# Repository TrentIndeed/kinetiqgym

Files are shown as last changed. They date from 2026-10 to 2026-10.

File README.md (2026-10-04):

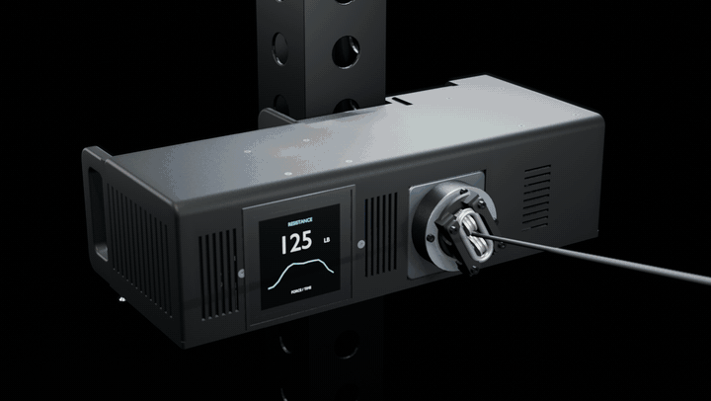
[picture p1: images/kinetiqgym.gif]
KinetiqGym: covers off, the drivetrain turning
<p align="center"></p>

<h1 align="center">KinetiqGym</h1>
<p align="center"><b>An open-source, battery-powered cable trainer you can print, build and modify.</b><br>
<a href="https://kinetiqgym.com">kinetiqgym.com</a> · <a href="docs/build.md">Build</a> · <a href="docs/wiring.md">Wiring</a> · <a href="bom/BOM.md">Parts</a> · <a href="cad/">CAD</a> · <a href="images/animation.mp4">Video</a></p>

A direct-drive motor turns a rope drum, a geared level-wind fairlead lays the rope, and the controller sets the resistance.
Designed to be 3D printed (with two drilled aluminium bars) or machined, and to be adapted: other motors, other batteries,
a rotary encoder instead of the touch screen.

> **Status: v0.1.0, prototype design. Not yet built or load-tested.** Read [SAFETY.md](SAFETY.md) before building.
> The control app is not included yet.

**Upcoming:** updated CAD models, the confirmed parts list and build instructions, phone/touchscreen apps, and Pi/Teensy programs. The files here are an earlier prototype snapshot. The website includes an [illustrated CNC build preview](https://kinetiqgym.com/docs/cnc-build-preview.html), mechanism camera views and app concepts from the latest animation.

Want to help? [Propose an improvement](https://github.com/TrentIndeed/kinetiqgym/issues/new?template=proposal.yml), read the [maintainer review process](CONTRIBUTING.md), or visit [project support](https://kinetiqgym.com/#support) for CNC equipment and prototype testing.

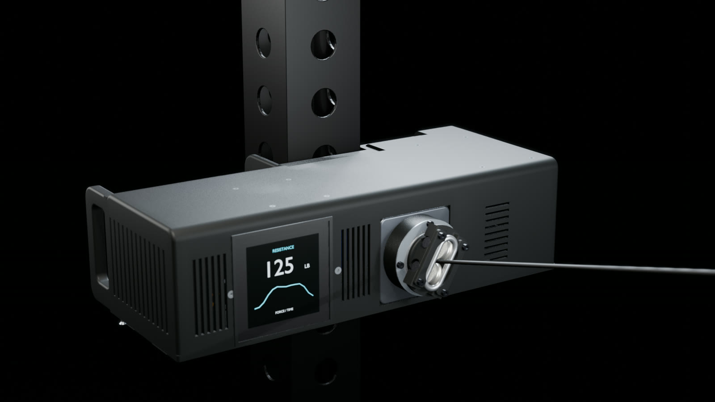
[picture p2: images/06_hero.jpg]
KinetiqGym on a rack upright


| | |
|---|---|
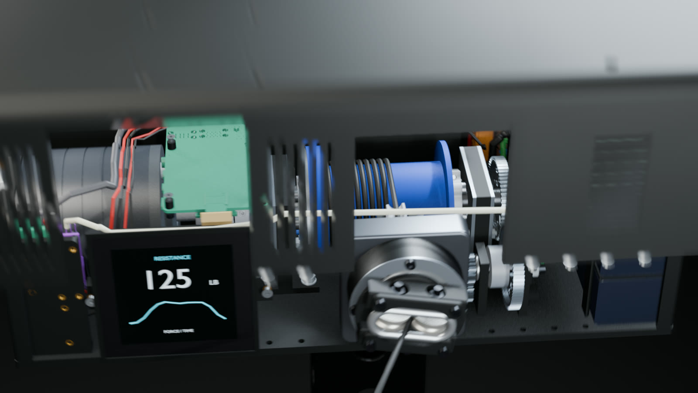
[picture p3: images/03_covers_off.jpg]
Covers off
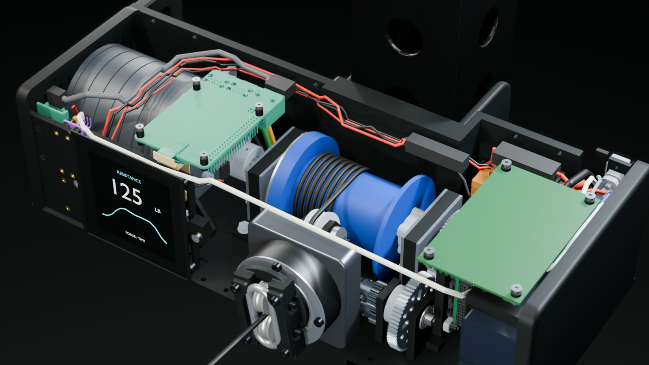
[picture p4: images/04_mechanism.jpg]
The mechanism
|  |  |
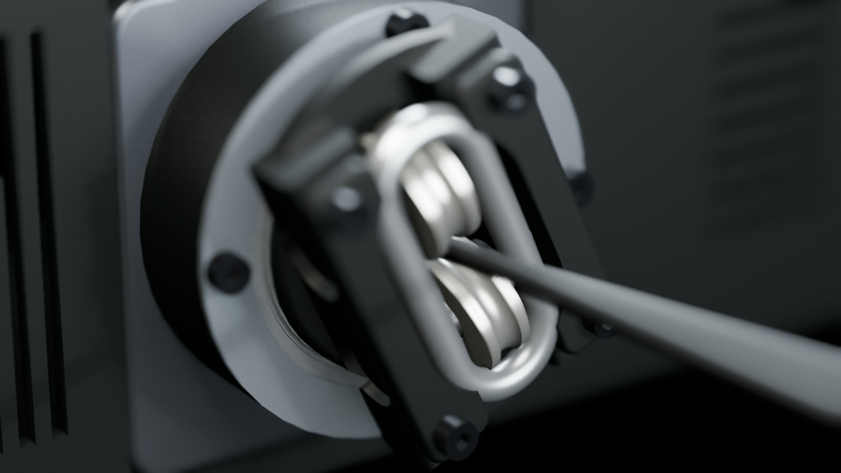
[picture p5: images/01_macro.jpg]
The fairlead exit
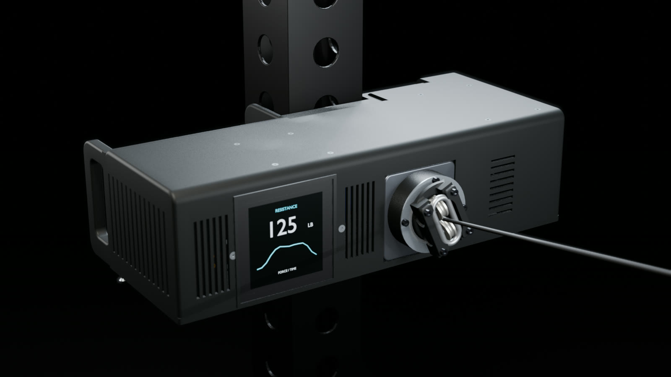
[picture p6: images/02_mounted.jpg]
Mounted on a rack
|  |  |
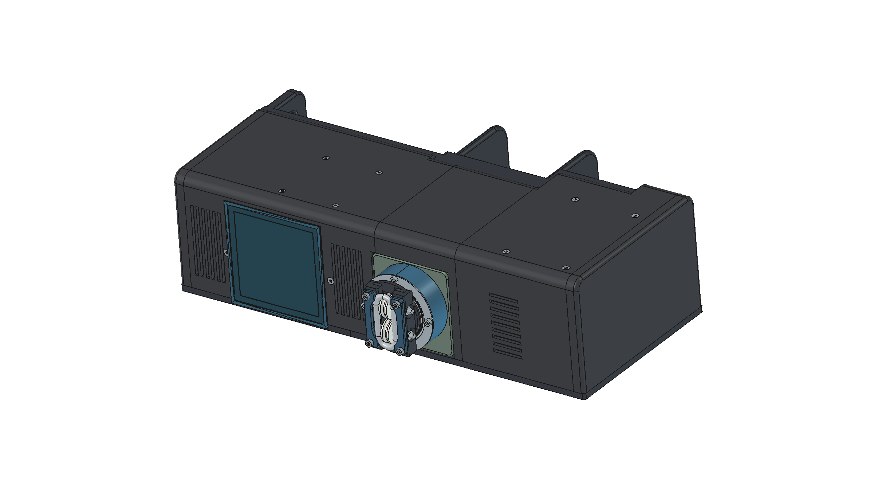
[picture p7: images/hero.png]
The CAD, covers on
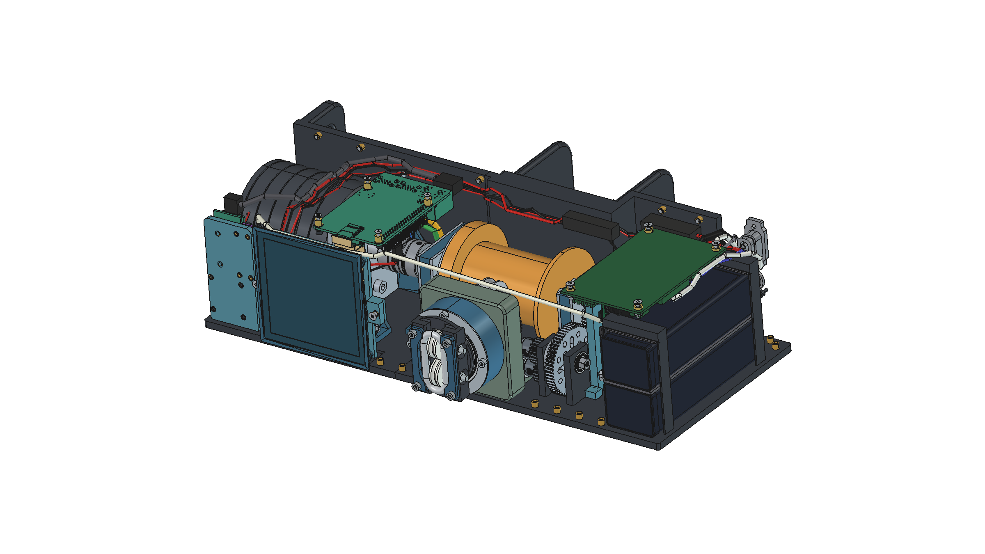
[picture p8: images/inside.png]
The CAD, covers off
|  |  |

<sub>Renders: Blender (Eevee) from the CAD in this repository, the mechanism moving at its real gear ratios; the display
content is illustrative. Bottom row: the FreeCAD assembly.</sub>

## At a glance

| | |
|---|---|
| Drive | direct-drive outrunner (reference: about 50 Kv, 13 N·m peak) on an ODrive Pro |
| Resistance | 100 lbf sustained design target; physical load and thermal validation pending |
| Rope | 3.175 mm (1/8 in), 2.11 m tracked payout + 3 dead wraps; design load 890 N (200 lbf) |
| Fairlead | worm-driven carrier (1/53 of a turn per drum turn) with a sheave and a U625ZZ pulley exit |
| Battery | 2 x 5S LiPo (Thunder Power TP2700-5SR70) in series, 30-42 V, JBD 10S BMS; regenerative braking charges it |
| Controls | Raspberry Pi 4 + 4 in touch screen, Teensy 4.0 on CAN to the ODrive |
| Size | about 371 x 143 x 112 mm, about 6 L, about 5.6 kg (estimate) |
| Parts | 28 printed parts, 136 screws / nuts / washers / inserts, about 55 purchased components |

## What is in this repository

| Folder | Contents |
|---|---|
| [`cad/freecad/`](cad/freecad/) | FreeCAD 1.x: the assembly, one file per part **with its full feature history**, and a drivetrain motion study |
| [`cad/step/`](cad/step/) | every part as STEP, plus one assembly STEP per variant |
| [`cad/dxf/`](cad/dxf/) | 2-D profiles of the flat parts |
| [`cad/vendor/`](cad/vendor/) | where to download the supplier CAD (bearings, gears, boards...) that cannot be redistributed |
| [`print/`](print/) | STL for every printed part, with material, orientation and inserts; fit coupons |
| [`bom/`](bom/) | bill of materials: purchased parts, hardware counts, metal |
| [`docs/`](docs/) | [build](docs/build.md), [wiring](docs/wiring.md), [electronics and firmware setup](docs/firmware-setup.md), [printing](docs/printing.md), [modifying](docs/modifying.md) |
| [`site/`](site/) | Website, editable itemized budget and reference pages |
| [`software/`](software/) | Pi, Teensy and companion software status (implementation pending) |
| [`source/`](source/) | the Python (CadQuery) scripts that generate the CAD |

Two variants share the same enclosure: **printed** (PA-CF bottom plate on two aluminium flat bars) and **cnc**
(aluminium bottom plate).

## Licences

- Hardware (CAD, drawings, print files): **CERN-OHL-S-2.0**
- Documentation and images: **CC BY-SA 4.0**
- Software and scripts (`source/`): **GPL-3.0**

See [LICENSE.md](LICENSE.md). Supplier CAD is not included; each supplier's own terms apply to the files you download.

## Contributing

Issues and pull requests are welcome: see [CONTRIBUTING.md](CONTRIBUTING.md).

## Development status and budget

See [the roadmap](docs/roadmap.md) for release milestones and [the website](https://kinetiqgym.com/#parts) for itemized purchasing prices, dated sources and editable fabrication allowances. The budget is a planning estimate, excluding tax, shipping, tools, labor and the rack.

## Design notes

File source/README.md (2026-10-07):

# Build scripts (GPL-3.0)

The Python / CadQuery scripts that generate every part, the fasteners, the wiring and the FreeCAD files.
They are the source of truth for the CAD. In this release they still expect the full design workspace (supplier CAD and the
interactive layout data are not published), so treat them as readable source; a self-contained build is planned.

- `print-v44/run_v44.sh`: the V44 pipeline (parts -> structure -> enclosure -> fasteners -> wiring -> checks)
- `mounts-rev11/`: brackets, saddles, board plates; `stock-drive-study/`: the fairlead module
- `fchist/`: records the CadQuery history and writes the FreeCAD files; `release/`: builds this repository

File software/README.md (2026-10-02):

# Control software — planned

No installable KINETIQ Pi application, Teensy firmware or Bluetooth companion is included in this release. The product film demonstrates the intended interface only.

Planned locations:

- `pi/`: built-in touchscreen application; resistance, rep graph and mode controls.
- `teensy/`: real-time control, position limits and ODrive communication.
- `companion/`: Bluetooth browser interface, richer settings and workout history.

These directories will be added with their implementations. Follow [the roadmap](../docs/roadmap.md) and [electronics setup reference](../docs/firmware-setup.md) for project status.

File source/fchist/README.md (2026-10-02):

# fchist: the V44 parts in FreeCAD, with their feature history

The Python build scripts stay the source of truth. While they run with `FCHIST=1`, every CadQuery modelling call is
recorded, and `to_freecad.py` turns that record into FreeCAD part files with a real feature tree: primitives,
booleans, fillets and moves that you can open, read and edit.

```
record_run.sh       one pipeline run with recording on (fairlead module -> rev-11 mounts -> V44 pipeline; same geometry)
make_freecad.sh     FreeCAD files -> cad/single-cable/freecad/<printed|cnc>/   (./make_freecad.sh [printed|cnc|both] [part prefix ...])
```

## What you get

`freecad/<variant>/V44_<variant>_assembly.FCStd` links every part (one `App::Link` per part, grouped by subsystem, coloured,
the "complete" view shown). A part that takes heat-set inserts is an `App::Part` holding the part and its inserts, so they move together. Each part is its own file in `freecad/<variant>/parts/<part>.FCStd`.

Open a part and expand its tree. The top feature is the finished part and holds the whole build:

| Pipeline call | FreeCAD feature |
|---|---|
| `Solid.makeBox / makeCylinder / makeCone / makeSphere / makeTorus` | `Part::Box / Cylinder / Cone / Sphere / Torus` (size + Placement) |
| `cut`, `fuse`, `intersect` | `Part::Cut` (several tools: a `MultiFuse` of the tools), `Part::MultiFuse`, `Part::MultiCommon` |
| `translate`, `rotate`, `moved`, `transformShape`, page placements | the Placement of the feature they move |
| `mirror` | `Part::Mirroring` |
| `clean` | `Part::Refine` |
| `fillet`, `chamfer` | `Part::Fillet`, `Part::Chamfer` (edges found again by position) |
| `Compound.makeCompound` | `Part::Compound` |
| anything else (wire extrusions, text, sweeps, picking one solid, supplier CAD, mesh-rebuilt page parts) | a `Base:` feature holding the exact shape |

Each feature's label names the script line that made it (for example `Cut · build_v44_shell.py:142 body`), and Label2 holds
the full call site. Change a primitive's size or placement and recompute: everything after it in the tree follows.

Every part is checked against the pipeline's own shape (volume and bounding box) in `freecad-report.json`.
If a rebuilt tree does not match, the part keeps its tree and shows the exact shape on top, and the report lists it.

## Drivetrain motion (FreeCAD Assembly workbench)

`freecad/<variant>/V44_<variant>_drivetrain_motion.FCStd` (`./make_freecad.sh both --motion`, `motion.py`) is a real
Assembly-workbench study, solved by FreeCAD's own solver:

- the motor body is grounded; Revolute joints on the drum shaft, shaft 2, the worm shaft and the carrier ring (6809 pivot);
- every part that turns with a shaft is Fixed to it; **Gears** joints carry drum 60T -> shaft-2 60T and shaft-2 20T -> worm-shaft 20T;
- FreeCAD has no worm-gear joint, so the carrier ring has its own motion at exactly 1/53 of the drum (direction checked: the
  worm and ring teeth never overlap through a worm turn);
- **Simulation: motor** drives the drum +-5.5 turns over 20 s (carrier +-37 deg, inside its +-48.4 deg stops).

Open the file, switch to the Assembly workbench, double-click *Simulation: motor*, press **Run** (about 3 minutes for the
1,000 frames), then **Play** or drag the frame slider. The covers are hidden; show them from the Static parts group.
Change the motor in the *Motor: drum shaft* motion (formula in radians of time, e.g. `6.28*time` = 1 turn/s; then set the
carrier motion to the same formula divided by 53). Keep the drum under about 13 deg per frame or the gear joints lose track.

## How it works

- `boot/sitecustomize.py` installs `fchist_rec.py` when `FCHIST=1` and `fchist/boot` is on `PYTHONPATH`. The build scripts are
  unchanged, apart from two direct OCP moves that now report themselves (`build_v44_phase1.py apply()`, `teensy_fit.py`).
- Each written part file gets `<file>.fch.json` (the graph back to the first primitive, with the file's hash). Reading the file in the
  next stage continues the same history, so a part made in `build_mounts.py`, placed in phase 1, cut by the shell and drilled by
  the fasteners step is one tree. Base shapes are stored once, by content hash, in `cad/single-cable/.fchist/blobs/` (not committed).
- History files are only trusted when the part file's hash matches, so a part rebuilt without recording falls back to its exact shape.

## Next (open-source path)

Sketches: replace the `Base:` features that come from wire extrusions (wire loops, gussets, polyline profiles) with
FreeCAD Sketcher sketches + Pad, and draw the plates and brackets from sketches instead of boxes, so the
release has editable 2-D profiles (and DXF) as well as the history.

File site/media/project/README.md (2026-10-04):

# Film stills for the project website

Source: `KINETIQ_67s_sequential_16x9_clean_shadow.mp4`, the approved Blender film with a CNC build followed by the phone app showcase.

| Image | Source |
| --- | --- |
| base.webp | 36.5 s, welded aluminum structure |
| drum.webp | 43.0 s, installed drum and fairlead |
| electronics.webp | 46.7 s, open CNC assembly |
| cover.webp | 51.4 s, finished enclosure |
| drive-angle.webp | 8.5 s, oblique mechanism view, narrator inset cropped out |
| gear-angle.webp | 11.5 s, front mechanism view, narrator inset cropped out |
| app-train/live/session/history.webp | High-resolution UI source pages used for the film |

These are design illustrations, not photographs of validated hardware or a working app. Keep that distinction when reusing them. The film assembly is a visualization revision; the updated manufacturing release remains pending.

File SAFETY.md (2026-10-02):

# Safety

**Status: prototype design. It has not been built or load-tested as published.** Treat every number here as a design value
until your own build has passed the tests below.

## What can hurt you

- **Cable load.** The machine is designed for 890 N (200 lbf) on the cable. A rope, an anchor or a printed part that fails
  under load releases that energy at the handle. Inspect the rope, the anchor wraps and the fairlead before every session;
  replace a frayed rope at once.
- **Battery.** Two 5S lithium-polymer packs in series make 30-42 V and can deliver very high current. Use the specified
  BMS and fuses, never bypass them, charge only with the BMS connected, and store and charge the packs on a fire-safe surface.
- **Motor torque.** The ODrive can drive the drum with up to about 13 N·m. Keep fingers, hair and loose clothing away from the
  drum, gears and the rope exit while it is powered.
- **Regenerative braking.** Lowering the weight charges the battery. If the BMS stops charging (full pack, over-temperature),
  the ODrive trips on over-voltage and **the cable goes slack for that rep**. Charge to about 80 % so braking energy has room.

## Rules for every build

1. **Payout limit in software.** Home the drum fully wound and set the ODrive position limits (`docs/firmware-setup.md`):
   `pos_min = 0`, `pos_max = 13.26` turns. The two hard stops on the fairlead carrier (+-48.4 deg) are only a backstop for
   assembly and hand-turning: the worm drive cannot be back-driven, so a stop hit under load locks the drum through the
   gears and can strip the m0.8 gears or break the printed lug.
2. **Keep the 3 dead wraps** of rope on the drum at full payout. Never run the rope off the drum.
3. **Fuses:** 40 A 58 V main fuse, 3 A 58 V regulator fuse, 7.5 A 58 V charge fuse. Automotive 32 V fuses are not rated for
   this pack voltage.
4. **First power-up** with the rope unloaded: check the inrush at the power button (the BMS may trip; lengthen its
   short-circuit delay in the BMS app if it does), the direction of the drum, the soft limits and the ODrive over-voltage trip.
5. **Load test** before training: hang a static load in steps up to 1.5 x your planned use, with nobody in the rope's path.
6. Print the structural parts in the specified material (PA-CF / PETG-CF), with the infill and walls in `docs/printing.md`,
   and print the fit coupons first.

## No warranty

The design is shared under the licences in `LICENSE.md` **without any warranty**. You build and use it at your own risk.

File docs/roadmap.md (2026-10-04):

# Project roadmap

KINETIQ is a prototype design. The repository contains an earlier development snapshot. Updated CAD, confirmed build instructions and parts list, app code and control programs are upcoming.

| Area | Available now | Next milestone |
|---|---|---|
| Hardware | Printed and CNC assemblies; FreeCAD feature histories, STEP, DXF and STL | Reconcile every export and manifest against one revision; prototype fit and load testing |
| Build guide | Draft references and an illustrated CNC animation preview on the website | Confirmed assembly steps, build photos and measured fit notes |
| Adaptation | Motor interface guide and battery-envelope sketch | Fully constrained sketch-based parts and a self-contained CAD generation pipeline |
| Raspberry Pi | Screen concept in the product film | Touchscreen application, reproducible image and installation guide |
| Teensy | Proposed control architecture and setup reference | Firmware, configuration schema, limits and bench test procedure |
| Companion | Phone app concept screens in the film and website | Bluetooth protocol, connection flow, mode settings and workout history |

## How releases should work

Keep one repository for the hardware, website, documentation and control software while the project is small. Each future release should identify a single compatible set of CAD, BOM, wiring and software versions. Do not mix a new part with an older assembly without recording the change.

For a hardware release, publish the editable FreeCAD sources and neutral STEP alongside STL/DXF exports, an itemized BOM, a changelog and a validation report. Label untested changes explicitly. Large production animations and build recordings belong in release assets or external media storage rather than repeated Git history.

For the Pi and Teensy, add actual source, dependency versions, build commands, configuration defaults and test instructions before advertising a software download. The current film is a UI concept, not evidence of working controls.

## Useful contributions

- Build reports: revision, manufacturing method, material, measured fit, photos and unresolved issues.
- CAD changes: source file, exported geometry, affected hardware and assembly steps.
- Alternative batteries or motors: interface dimensions, electrical compatibility assumptions and test results.
- Sourcing: exact part, region, quantity, price, currency, date and supplier link.
- Documentation: one reproducible step or correction with the affected revision.

See [CONTRIBUTING.md](../CONTRIBUTING.md) and [the license map](../LICENSE.md). Supplier CAD and controller firmware retain their own terms.

## Prototype funding

Project support is intended for a CNC machine, fabrication and prototype test equipment. The website support section explains these goals. A payment link appears only when the owner has configured the chosen donation provider; contributions are not orders for a finished product. No funding total or equipment price is implied by the concept film.

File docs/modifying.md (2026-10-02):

# Modifying the design

The design is meant to be adapted: a different motor, a rotary encoder instead of the touch screen, a different battery.
This release ships the parts as FreeCAD files with their full feature history and as STEP; fully sketch-based,
parameter-driven parts are planned for the next release.

## How the CAD is organised

- `cad/freecad/<printed|cnc>/V44_<variant>_assembly.FCStd`: the whole machine. Every part is a link to its own file in `parts/`.
  A part that takes heat-set inserts is a container holding the part and its inserts.
- `cad/freecad/<variant>/parts/<part>.FCStd`: one part with its feature tree (boxes, cylinders, cuts, fuses, fillets, moves).
  Each feature is labelled with the build-script line that made it. Change a size or a placement and recompute.
- `cad/freecad/<variant>/V44_<variant>_drivetrain_motion.FCStd`: Assembly-workbench motion study of the drivetrain.
- `cad/step/`: the same parts as STEP for any CAD program, plus one assembly STEP per variant.
- `cad/dxf/`: 2-D profiles of the flat parts.
- Supplier parts (motor driver, bearings, gears, boards...) are simple placeholders of the right size; get the real CAD
  from `cad/vendor/README.md`.
- `source/`: the Python (CadQuery) scripts that generate everything. They are the source of truth, but in this release they
  still expect the full design workspace; a self-contained build is planned.

Variants: **printed** (PA-CF bottom plate with aluminium flat bars under it) and **cnc** (aluminium bottom plate).

## Swapping the motor

What the motor touches:

| Interface | Where | Change |
|---|---|---|
| Face mount | the 4 mm motor face plate (`V43_METAL_motor_face_4mm`) + two printed gussets | hole pattern and pilot bore for your motor |
| Shaft | the NBK MSTS-25-10-12 coupling (10 mm motor, 12 mm drum shaft) | coupling bore for your shaft |
| Envelope | motor body about 80 x 82 mm at the motor end (X -77 to -3) | the end cap, covers and the board plate around it |
| Leads | three phase leads through a 12 mm grommet in the face plate to the ODrive terminal | lead exit and length |
| Electrical | ODrive Pro limits (current, voltage), torque constant | `firmware-setup.md` |

Torque at the drum is the motor torque (direct drive): the cable force is about torque / 0.025 m (rope radius on the drum).

## Swapping the batteries

1. Measure both actual packs, including leads and connector bodies. Record length, width and height; do not rely only on nominal capacity.
2. Open a copy of the assembly and the saddle/retainer part files. Edit the relevant feature dimensions. For a STEP-only workflow, import the solids, create a constrained rectangular envelope sketch, and use new additive/subtractive features for your revised mount.
3. Add padding and lead-bend clearance to the envelope. Keep the BMS, wires and mounting screws outside the straight removal path. Test both pack envelopes together, including staggered removal.
4. Recompute the covers and check intersections and retaining surfaces. Print a fit sample before committing to a full enclosure; export the updated STEP/STL and update the BOM and revision.
5. Review series count, fully charged voltage, BMS, charger, fuse/wire sizing and regenerative charge limits as a system before powered testing. Capacity alone does not establish compatibility.

The reference is two 5S packs in series (10S, 42 V fully charged). The [website adaptation guide](https://kinetiqgym.com/#modify) illustrates the pack envelope and motor interfaces. Its diagrams are measurement guides, not dimensioned manufacturing drawings.

## Rotary encoder instead of the touch screen

What the screen touches:

| Interface | Where | Change |
|---|---|---|
| Front window | the left cover (`V44_PRINT_cover_left_screen`), 4 in window | replace the window with a panel hole for the encoder (and a small display if wanted) |
| Screen frame | `MOUNT_screen_rear_retaining_frame_printed` + 2 x M3 legs into inserts | not needed |
| Pi + DSI ribbon | Raspberry Pi 4 hanging from the cover ceiling, ribbon to the screen | optional: the Teensy can run the machine alone |
| Encoder | quadrature A/B + push switch to free Teensy pins, 3.3 V | firmware |

## Contributing changes back

The hardware is CERN-OHL-S-2.0 (share-alike): if you distribute a modified version, publish your modified design files under
the same licence. Pull requests and issues are welcome: see `CONTRIBUTING.md`.

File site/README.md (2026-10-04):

# KINETIQ website

Static HTML, CSS and JavaScript. Serve this directory over HTTP:

```sh
python -m http.server 8770 --directory site
```

The editable shopping budget uses `data/project.json`; each row records quantity, unit price, price basis, applicable build and source. Unknown costs are explicit allowances. Prices are not live inventory or quotes. User edits and owned-item selections stay in browser local storage; CSV export includes the selected build.

`docs/` contains readable HTML copies of the public Markdown references. Keep both copies aligned when changing engineering documentation. The website does not contain the private hosting account configuration.

The illustrated CNC build and phone app are concept previews extracted from the Blender film. The updated CAD release, confirmed parts list, final build instructions and control software are pending. Do not present them as validated downloads.

`data/community.json` contains the public proposal email and donation checkout URL. Empty fields show honest “coming soon” states. Set `proposalEmail` to the owner's approved public address and `donationUrl` to an HTTPS checkout on the chosen provider; `donationProvider` names it in the checkout description. Payments are handled by that provider, not collected on this website. No donation totals or equipment budget are invented.

The website links to the public GitHub proposal form and contribution guide. The initial review owner is `@TrentIndeed`; `.github/CODEOWNERS` and the main-branch ruleset enforce reviews for community changes. Additional moderators must be appointed by the repository owner.

The four illustrated stages have a standalone guide in `docs/cnc-build-preview.md` and `.html`. When replacing film stills, keep their revision and concept status clear.

The owner-approved public proposal address is `trentondragon02@gmail.com`. The owner-supplied PayPal donation URL is active and its recipient was verified as Trenton Dragon on the PayPal checkout page. The goal is a Carvera Air CNC machine and prototype testing. Preserve the recipient ID and checkout parameters when editing the link; do not substitute the proposal email as a payment recipient.

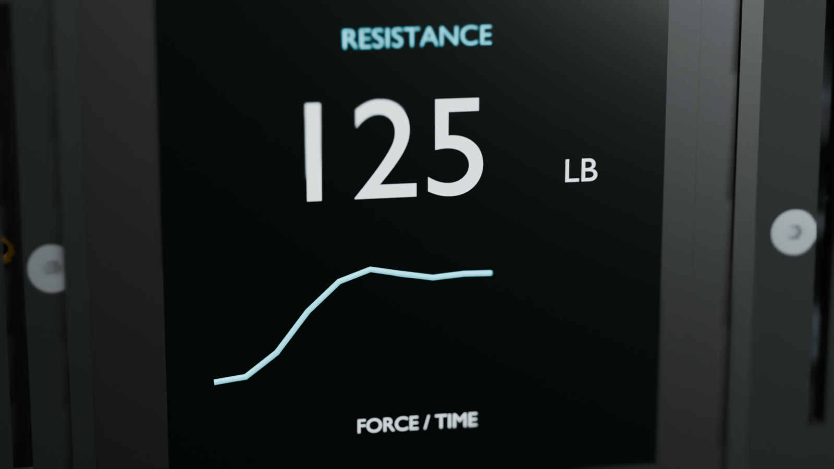
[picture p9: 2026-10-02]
site/media/05_display.jpg

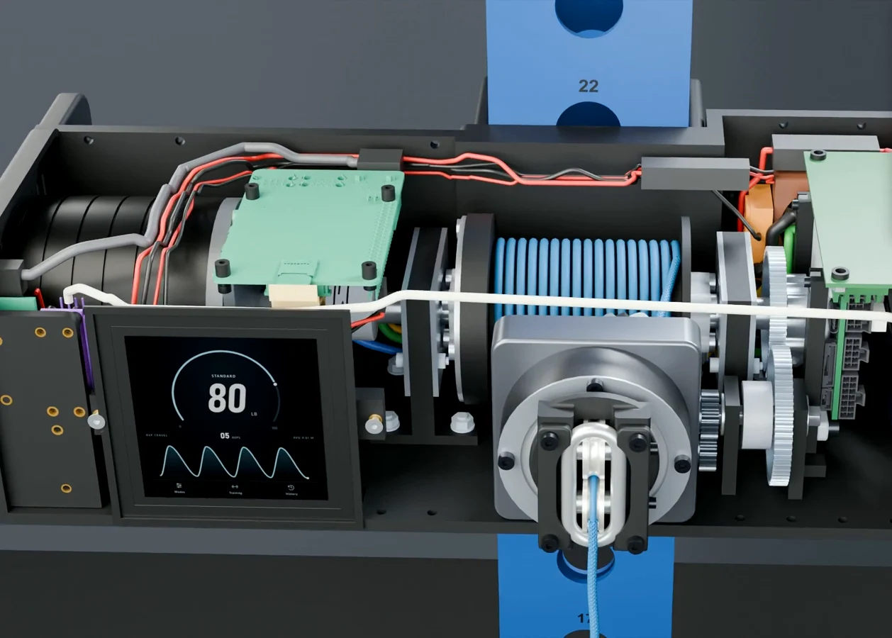
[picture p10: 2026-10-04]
site/media/project/gear-angle.webp

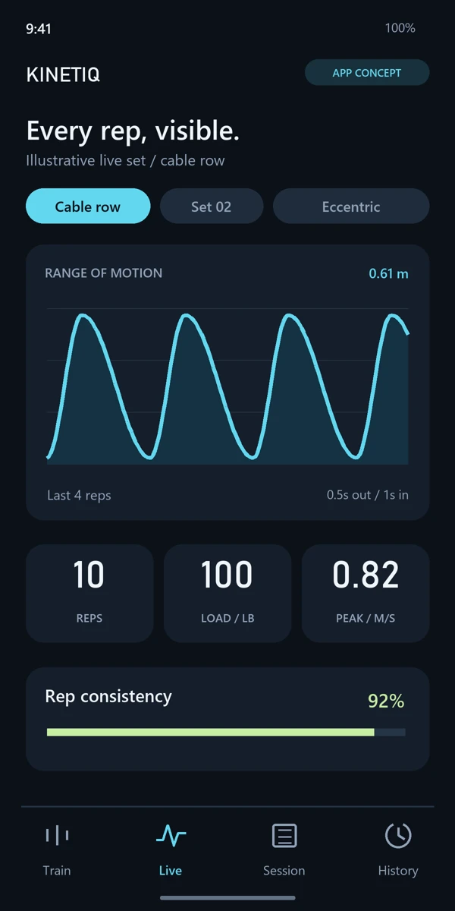
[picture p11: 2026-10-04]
site/media/project/app-live.webp

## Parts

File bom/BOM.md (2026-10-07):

# Bill of materials

Quantities are for one machine (printed variant). Links are examples checked in September 2026: pick by reviews and check the
specs. Nothing here is endorsed by the suppliers.

## Drive and fairlead

| Qty | Part | Notes / example |
|---|---|---|
| 1 | Outrunner motor, about 80 mm diameter, about 50 Kv, about 13 N·m peak, 10 mm shaft | the reference design; see `docs/modifying.md` to use another |
| 1 | ODrive Pro motor controller (with its heat spreader) | odriverobotics.com |
| 1 | NBK MSTS-25-10-12 slit coupling (10 mm motor / 12 mm drum shaft) | or any 25 mm clamp coupling 10-12 |
| 1 | 12 mm round steel shaft, cut to 176 mm | drum shaft |
| 2 | 6001-2RS bearing (12 x 28 x 8) | drum shaft, in the printed cartridges |
| 2 | goBILDA 1301-0016-0012 12 mm round-bore hub | drum hubs (4 mounting holes drilled 4.4 mm) |
| 2 | goBILDA 2302-0014-0060 60T MOD 0.8 gear | drum gear + shaft-2 gear (48 mm centres) |
| 1 | goBILDA 2303-4008-0020 20T MOD 0.8 pinion, 8 mm REX | [gobilda.com](https://www.gobilda.com/2303-series-steel-mod-0-8-pinion-gear-8mm-rex-bore-20-tooth/) |
| 1 | goBILDA 2303-1006-0020 20T MOD 0.8 pinion, 6 mm D-bore | [gobilda.com](https://www.gobilda.com/pinion-gears/) |
| 1 | goBILDA 2106-4008-0560 8 mm REX shaft 56 mm with e-clip | [gobilda.com](https://www.gobilda.com/2106-series-stainless-steel-rex-shaft-8mm-diameter-56mm-length/) |
| 2 | goBILDA 1611-0514-4008 flanged bearing 8 mm REX x 14 x 5 | [gobilda.com](https://www.gobilda.com/1611-series-flanged-ball-bearing-8mm-rex-id-x-14mm-od-5mm-thickness-2-pack/) |
| 1 | ServoCity 6 mm stainless D-shaft, 60 mm | [servocity.com](https://www.servocity.com/6mm-stainless-steel-d-shafting/) |
| 2 | goBILDA 1601 flanged bearing 6 x 14 x 5 | [gobilda.com](https://www.gobilda.com/1601-series-flanged-ball-bearing-6mm-id-x-14mm-od-5mm-thickness-2-pack/) |
| 1 | KHK SW0.8-R1 steel worm, module 0.8, single start, right hand | [khkgears.us](https://catalog.khkgears.us/item/worm-gears/steel-worms-sw/sw0-8-r1) |
| 1 | 6809-2RS bearing 45 x 58 x 7 (carrier pivot) | e.g. [Amazon](https://www.amazon.com/dp/B07RVJJPVG) |
| 2 | 6808-2RS bearing 40 x 52 x 7 (exit swivel) | |
| 2 | 625ZZ bearing 5 x 16 x 5 (rope-turn roller) | e.g. [Amazon](https://www.amazon.com/dp/B07MXCQSMD) |
| 2 | 688ZZ bearing 8 x 16 x 5 (top sheave) | |
| 2 | uxcell U625ZZ nylon U-groove pulley 5 x 20 x 7 (exit) | |
| 2 | ISO 7379 shoulder bolt 5 x 25, M4 + 4 x M5 2 mm shims | exit pulley axles |
| 1 | 8 mm axle / bolt for the sheave, 5 mm shoulder screw for the roller | see the fairlead parts |
| - | Rope, 3.175 mm (1/8 in), about 3 m | e.g. UHMWPE; rated well above the 890 N design load |

## Power

| Qty | Part | Example |
|---|---|---|
| 2 | Thunder Power TP2700-5SR70 5S LiPo (EC5 leads) | in series = 10S |
| 1 | JBD / LLT SP17S005 10S BMS, 60 A, with soft switch and NTC | |
| 1 | Littelfuse 04980921GXM5 MIDI 58 V fuse holder, M5 studs | [Waytek](https://www.waytekwire.com/product/littelfuse-inline-midi-fuse-holder-04980921gxm5) |
| 1 (+1) | Littelfuse BF1 142.5631.5402 40 A 58 V fuse | [National Fuse](https://nationalfuse.com/shop/142-5631-5402/) |
| 2 (+2) | Littelfuse 997 MINI 58 V fuses: 3 A (0997003.WXN) and 7.5 A | [Newark](https://www.newark.com/littelfuse/0997003-wxn/automotive-fuse-fast-acting-3a/dp/79J5391) |
| 2 | Inline MINI fuse holder with cover, 16 AWG | e.g. [VANTRONIK](https://www.amazon.com/dp/B07MQZ9Q8L) |
| 1 | WAGO 221-615 5-port lever nut | e.g. [WAGO 15-pack](https://www.amazon.com/dp/B07CJR8MH4) |
| 1 | AMASS XT60E-F female panel socket (charge port) | e.g. [Amass](https://www.amazon.com/dp/B09SL2MNN1) |
| 1 | 12 mm latching push switch with ring LED (power button) | e.g. [APIELE](https://www.amazon.com/dp/B083QMF2J1) |
| - | EC5 connector pairs, 5S JST-XH balance leads | e.g. [EC5](https://www.amazon.com/dp/B08GPR7SVR), [XH leads](https://www.amazon.com/dp/B073ZGF8D9) |
| - | Silicone wire 10 / 12 / 16 / 18 / 20 / 22 / 24 AWG, ferrules, M5 ring terminals | see `docs/wiring.md` for lengths |
| 1 | Charger: 10S Li-ion/LiPo, XT60, 4 A | |

## Electronics

| Qty | Part |
|---|---|
| 1 | Raspberry Pi 4 Model B |
| 1 | Waveshare 4 in DPI LCD (C), 720 x 720 touch, with its 15-way FFC |
| 1 | Teensy 4.0 + 2 x 14-pin low-profile female headers |
| 1 | Waveshare SN65HVD230 CAN board |
| 1 | Pololu D42V55F5 5 V 5.5 A regulator (#5571) |
| 1 | Noctua NF-A4x10 5V fan |
| 3 | Perfboards (Teensy, CAN, regulator), cut to the outlines in the CAD |
| 1 | Right-angle micro-USB to right-angle USB-A cable, short |

## Structure and consumables

| Qty | Part |
|---|---|
| 2 | 6061 aluminium flat bar 1 x 1/4 x 12 in (drilled, used uncut) |
| - | PA-CF filament about 1 kg; PETG-CF or PA-CF for the covers about 0.5 kg (see `print/README.md`) |
| - | 1 mm and 2 mm EVA foam sheet (battery pads) |
| - | Cable ties, thread-locker |

## Screws, nuts and heat-set inserts

Generated by `print-v44/hardware_summary.py` from the model (every F44_* screw / nut / washer / insert, plus the exit
axles, ceiling standoffs and Teensy socket headers). Counts are exact for each build; buy packs (assortment kits cover most
screws). Printed = the PA-CF / PETG prototype; CNC = the aluminium-plate build. Nothing is ordered.

| Item | Printed | CNC |
|---|---:|---:|
| M2.5 heat-set insert L4 (Ruthex RX) | 10 | 10 |
| M3 heat-set insert L4 (Ruthex RX) | 22 | 24 |
| M4 heat-set insert L4 (Ruthex RX) | 18 | 4 |
| M2.5x4 socket head (ISO 4762) | 3 | 3 |
| M2.5x5 countersunk (ISO 10642) | 6 | 6 |
| M2.5x5 socket head (ISO 4762) | 2 | 2 |
| M2.5x6 socket head (ISO 4762) | 1 | 1 |
| M2.5x10 socket head (ISO 4762) | 4 | 4 |
| M2.5x12 socket head (ISO 4762) | 6 | 6 |
| M3x6 socket head (ISO 4762) | 2 | 2 |
| M3x8 countersunk (ISO 10642) | 12 | 15 |
| M3x8 socket head (ISO 4762) | 2 | - |
| M3x10 countersunk (ISO 10642) | 5 | 9 |
| M3x10 socket head (ISO 4762) | - | 2 |
| M3x12 countersunk (ISO 10642) | 4 | 4 |
| M3x16 countersunk (ISO 10642) | 1 | - |
| M3x25 countersunk (ISO 10642) | 4 | 4 |
| M4x10 countersunk (ISO 10642) | 16 | 4 |
| M4x12 socket head (ISO 4762) | 4 | 4 |
| M4x16 countersunk (ISO 10642) | 2 | - |
| M6x16 countersunk (ISO 10642) | - | 4 |
| uxcell U625ZZ nylon U-groove pulley bearing 5 x 20 x 7 | 2 | 2 |
| M2.5 female-female brass hex standoff 3 mm | 4 | 4 |
| M3 female-female brass hex standoff / spacer 2 mm | 4 | 4 |
| M3 nyloc nut (ISO 10511) | 4 | 4 |
| M3 washer (ISO 7089) | 4 | 4 |
| M4 hex nut (ISO 4032), in its pocket | 4 | 4 |
| M4 nyloc nut (ISO 10511) | 2 | 2 |
| M4 washer (ISO 7089) | 2 | 2 |
| M5 spacer / shim washer 2 mm (5.2 ID) | 4 | 4 |
| 2.54 mm 14-pin female socket header, low profile (Teensy on the perfboard) | 2 | 2 |
| Shoulder bolt ISO 7379, 5 mm shoulder x 25, M4 thread | 2 | 2 |
| **Total pieces** | **158** | **142** |

## Shopping by kit (printed build)

- **M2.5 countersunk screws:** 6 x 5 mm
- **M2.5 socket head screws:** 3 x 4 mm, 2 x 5 mm, 1 x 6 mm, 4 x 10 mm, 6 x 12 mm
- **M3 countersunk screws:** 12 x 8 mm, 5 x 10 mm, 4 x 12 mm, 1 x 16 mm, 4 x 25 mm
- **M3 socket head screws:** 2 x 6 mm, 2 x 8 mm
- **M4 countersunk screws:** 16 x 10 mm, 2 x 16 mm
- **M4 socket head screws:** 4 x 12 mm
- **heat-set inserts (Ruthex RX, L4):** 22 x M3, 18 x M4, 10 x M2.5
- **nuts / washers:** 4 x M3 nyloc nut (ISO 10511), 4 x M3 washer (ISO 7089), 4 x M4 hex nut (ISO 4032), in its pocket, 2 x M4 nyloc nut (ISO 10511), 2 x M4 washer (ISO 7089), 4 x M5 spacer / shim washer 2 mm (5.2 ID)

Hole sizes the model is cut to (tune with `fit-coupons/`): inserts M2.5 3.6 / M3 4.0 / M4 5.6 mm, printed clearance
M2.5 2.9 / M3 3.6 / M4 4.7 / M6 6.8 mm, self-tap pilots M2.5 2.2 / M3 2.6 mm.

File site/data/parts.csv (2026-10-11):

id | name | category | qty | price | note | url | status | build | date | motor | list
p086 | MP80100 outrunner, 50 Kv, sensored | Drive | 1 | 260 | Freerchobby, via AliExpress: $230 + $30 shipping, ships from China (3-4 weeks). Cut its bell-end prop shaft to a 10 mm stub. | https://www.aliexpress.us/item/3256805081566856.html | Recorded price | both | Checked Oct 7, 2026 | mp80100 mp80100_220 | main
p001 | APS 8072S outrunner, 50 Kv | Drive | 1 | 220 | Alien Power Systems, UK: about £169 plus shipping. The main build's motor. |  | Estimate | both |  | aps8072s | main
p121 | APS 8072S outrunner, custom ~25 Kv | Drive | 1 | 230 | Alien Power Systems winds it to order: ask for about 25 Kv (the stock motor is 50 Kv). Same body, mount and 10 mm keyed shaft as the main build. Not quoted yet. |  | Estimate | both |  | lite150 | main
p087 | Ruland MCLX-12-12-F clamp coupling | Drive | 1 | 35 | One-piece steel, 12 mm motor / 12 mm drum, 105 N·m. About £22 ex VAT in the UK; US price at ruland.com. | https://www.ruland.com | Estimate | both |  | mp80100 mp80100_220 c80100_220 | main
p114 | Ruland MCLX-12-10-F clamp coupling | Drive | 1 | 35 | One-piece steel, 10 mm motor / 12 mm drum. | https://www.ruland.com | Estimate | both |  | aps8072s lite150 | main
p089 | M5 aluminium spacers, pack | Drive | 1 | 7 | Motor to the face plate: 10 mm long for the MP80100 and C80100, 3 mm for the APS 8072S (4 needed). |  | Estimate | both |  | all | main
p006 | 12 mm steel drum shaft | Drive | 1 | 15 | The drum shaft, 200 mm, used uncut. |  | Estimate | both |  | all | main
p002 | ODrive Pro ODv44-ST | Drive | 1 | 229 | Controller only; heat spreader is separate. 70 A continuous: the 220 lb choices use a lower-Kv motor to stay inside it. | https://shop.odriverobotics.com/products/odrive-pro | Source price | both | Checked Oct 2, 2026 | aps8072s mp80100 mp80100_220 c80100_220 | main
p003 | ODrive Pro heat spreader | Drive | 1 | 25 | Thermal hardware allowance. | https://shop.odriverobotics.com/ | Estimate | both |  | aps8072s mp80100 mp80100_220 c80100_220 | main
p122 | ODrive S1, solder-pad version | Drive | 1 | 149 | 40 A continuous on its heat spreader, 80 A peak, 12-50.5 V, with an onboard magnetic encoder. Screws to a 6061 plate you make; the main build's ODrive bracket stays. In stock at ODrive (US) on Oct 10. | https://shop.odriverobotics.com/products/odrive-s1 | Source price | both | Checked Oct 10, 2026 | lite150 | main
p120 | APS C80100 outrunner, sensored, custom ~25 Kv | Drive | 1 | 290 | Alien Power Systems, UK: stock 50 Kv is £209 plus shipping (on backorder October 10); ask APS for the ~25 Kv winding and its price before ordering. Ø80 x 92, 4 x M5 on Ø56, 12 mm keyed shaft; cut its rear shaft to a 10 mm stub. | https://alienpowersystem.com | Estimate | both | Checked Oct 10, 2026 | c80100_220 | main
p007 | 6001-2RS bearings, 2-pack | Drive | 1 | 6.95 | Two bearings required. | https://www.amazon.com/dp/B07GVN7GQ7 | Recorded price | both | Oct 2, 2026 | all | main
p008 | goBILDA 1301-0016-0012 hub | Drive | 2 | 9.99 | Drum hub and 81T gear hub. | https://www.servocity.com | Estimate | both |  | all | main
p088 | Loctite 638 retaining compound, 10 mL | Drive | 1 | 20 | Bonds the drum hub and both drum flanges to the round shaft (or Loctite 648). | https://www.amazon.com/dp/B004GZDV8I | Estimate | both |  | all | main
p090 | goBILDA 1309-0016-0008 Sonic Hub, 8 mm | Level-wind | 1 | 7.99 | Carries the printed 45T gear on the lead screw. | https://www.servocity.com/1309-series-sonic-hub-8mm-bore/ | Source price | both | Checked Oct 5, 2026 | all | main
p091 | Tr8 x 2 lead screw, 200 mm, 2-pack | Level-wind | 1 | 11.99 | With brass flange nuts; used uncut. Pick "200mm / 2pcs Tr8X2". | https://www.amazon.com/dp/B0B8RKSDJV | Recorded price | both | Checked Oct 3-5, 2026 | all | main
p092 | MGN15H rail 200 mm with block, 2 sets | Level-wind | 1 | 49.99 | The traveller rail (one spare set). | https://www.amazon.com/dp/B0D7CLND4B | Recorded price | both | Checked Oct 3-5, 2026 | all | main
p093 | 626ZZ bearings, 10-pack | Level-wind | 1 | 9.99 | Travelling and fixed rollers, 8 needed. | https://www.amazon.com/dp/B07JHKBG4X | Recorded price | both | Checked Oct 3-5, 2026 | all | main
p094 | ISO 7379 shoulder bolts 6 x 16, M5, 6-pack | Level-wind | 1 | 8.99 | The four roller axles. | https://www.amazon.com/dp/B0DP6ZRSTT | Recorded price | both | Checked Oct 3-5, 2026 | all | main
p021 | 688ZZ bearings, 5-pack | Level-wind | 1 | 5.99 | Lead screw far end, in the printed stand. | https://www.amazon.com/dp/B08199J4RJ | Recorded price | both | Checked Oct 3-5, 2026 | all | main
p095 | MR128ZZ bearings, 10-pack | Level-wind | 1 | 7 | Lead screw fixed end, in the tower wall. | https://www.amazon.com/dp/B089GG2YCT | Estimate | both |  | all | main
p096 | F8-16M thrust bearings, 4-pack | Level-wind | 1 | 7.99 | Lead screw fixed end, both directions. | https://www.amazon.com/dp/B07QLTXJDH | Recorded price | both | Checked Oct 3-5, 2026 | all | main
p097 | 8 mm set-screw shaft collars, 10-pack | Level-wind | 1 | 8.89 | Preloads the thrust pair. | https://www.amazon.com/dp/B08SK2LNNV | Recorded price | both | Checked Oct 3-5, 2026 | all | main
p098 | 16008-2RS bearing 40 x 68 x 9 | Fairlead & rope | 2 | 9.59 | Exit swivel (sold singly). | https://www.amazon.com/dp/B07PPNVNYY | Recorded price | both | Checked Oct 3-5, 2026 | all | main
p099 | F6001-2RS flanged bearings, 4-pack | Fairlead & rope | 1 | 9.99 | Exit pulleys: the rope runs on the outer ring. | https://www.amazon.com/dp/B09BVV9BYZ | Recorded price | both | Checked Oct 3-5, 2026 | all | main
p100 | ISO 7379 shoulder bolts 12 x 20, M10, 2-pack | Fairlead & rope | 1 | 9.89 | Exit pulley axles. | https://www.amazon.com/dp/B0FDQY2795 | Recorded price | both | Checked Oct 3-5, 2026 | all | main
p101 | Dowel pins 5 x 60 mm, 304 stainless, 24-pack | Fairlead & rope | 1 | 8.49 | The exit's side rails. | https://www.amazon.com/dp/B0FZHR1NP3 | Recorded price | both | Checked Oct 3-5, 2026 | all | main
p024 | 1/8 in UHMWPE rope | Fairlead & rope | 1 | 15 | About 3 m. |  | Estimate | both |  | all | main
p027 | Thunder Power TP2700-5SR70 | Power | 2 | 102.99 | 5S 2.7 Ah LiPo, EC5 leads. Two packs in series. | https://www.thunderpowerrc.com/products/tp2700-5sr70 | Source price | both | Checked Oct 2, 2026 | aps8072s mp80100 mp80100_220 c80100_220 | main
p028 | 10S smart BMS, 60 A or more | Power | 1 | 45 | US-stocked pick in progress; the CAD is sized for a 102 x 65 x 12 mm board. |  | Estimate | both |  | aps8072s mp80100 mp80100_220 c80100_220 | main
p104 | Blue Sea 5191 MRBF terminal fuse block | Power | 1 | 30.78 | 58 V DC; upright on a printed insulating pad. | https://www.amazon.com/dp/B0019ZBTV4 | Recorded price | both | Checked Oct 3-5, 2026 | aps8072s mp80100 mp80100_220 c80100_220 | main
p105 | Blue Sea 5176 MRBF 40 A fuse | Power | 2 | 17.93 | 58 V DC; one spare. | https://www.amazon.com/dp/B0016HTXAY | Recorded price | both | Checked Oct 3-5, 2026 | aps8072s mp80100 mp80100_220 c80100_220 | main
p031 | MINI 58 V 3 A fuse | Power | 2 | 4 | 0997003.WXN; one installed plus spare. | https://www.newark.com/littelfuse/0997003-wxn/automotive-fuse-fast-acting-3a/dp/79J5391 | Estimate | both |  | all | main
p032 | MINI 58 V 7.5 A fuse | Power | 2 | 4 | One installed plus spare; verify 58 V rating. |  | Estimate | both |  | aps8072s mp80100 mp80100_220 c80100_220 | main
p106 | Inline MINI fuse holder, 58 V rated | Power | 2 | 6 | With cover, 16 AWG. Most holders are rated 32 V: buy from Digi-Key or Mouser. |  | Estimate | both |  | all | main
p034 | WAGO 221-615, 15-pack | Power | 1 | 24.39 | Five-port 10 AWG connector; one used. | https://www.amazon.com/dp/B07CJR8MH4 | Recorded price | both | Sep 2026 | aps8072s mp80100 mp80100_220 c80100_220 | main
p035 | Amass XT60E-F, 10-pack | Power | 1 | 9.88 | Panel charge socket; one used. | https://www.amazon.com/dp/B09SL2MNN1 | Recorded price | both | Sep 2026 | aps8072s mp80100 mp80100_220 c80100_220 | main
p036 | APIELE 12 mm latching switch, 2-pack | Power | 1 | 8.99 | BMS signal switch; LED not wired in reference. | https://www.amazon.com/dp/B083QMF2J1 | Recorded price | both | Sep 2026 | aps8072s mp80100 mp80100_220 c80100_220 | main
p037 | EC5 connectors, 10 pairs | Power | 1 | 15.99 | Retail pack for pack and BMS connections. | https://www.amazon.com/dp/B08GPR7SVR | Recorded price | both | Sep 2026 | aps8072s mp80100 mp80100_220 c80100_220 | main
p038 | 5S JST-XH balance leads, 10-pack | Power | 1 | 6.99 | Pack-to-BMS sense harness. | https://www.amazon.com/dp/B073ZGF8D9 | Recorded price | both | Sep 2026 | aps8072s mp80100 mp80100_220 c80100_220 | main
p107 | 42 V 2 A charger (10S) | Power | 1 | 16.99 | Fit an XT60 male plug (about 1.5 h per charge). | https://www.amazon.com/dp/B08JYSZX78 | Recorded price | both | Checked Oct 3-5, 2026 | aps8072s mp80100 mp80100_220 c80100_220 | main
p123 | Mean Well LOP-600-36 power supply | Power | 1 | 105.34 | 36 V open frame: 400 W by convection, 600 W with airflow, 150 % for 3 s. Jameco: $83.60 plus a 26 % tariff added at checkout; 3-week lead time, non-returnable. | https://www.jameco.com/z/LOP-600-36-MEAN-WELL-600W-Low-Profile-Energy-Efficient-Medical-Open-Frame-Power-Supply-36V-11-1A-Convection-16-7A-with-Fan_2410207.html | Source price | both | Checked Oct 10, 2026 | lite150 | main
p124 | uxcell C14 panel-mount inlet, 10 A, 2-pack | Power | 1 | 7.89 | The mains inlet, snapped into the back step. 4.8 stars (123), ships from Amazon. | https://www.amazon.com/dp/B07PVP7GL2 | Source price | both | Checked Oct 10, 2026 | lite150 | main
p125 | KCD1 rocker switch, 10 A 125 V / 6 A 250 V | Power | 1 | 3.98 | Mains on/off in the line lead, beside the inlet. 4.3 stars (42), ships from Amazon. | https://www.amazon.com/dp/B0DX1JY5BW | Source price | both | Checked Oct 10, 2026 | lite150 | main
p126 | uxcell 50 W 1 Ω aluminium resistors, 5-pack | Power | 1 | 8.54 | Two in series (2 Ω) as the S1's brake resistor, screwed flat to the base plate, which is their heatsink. 5.0 stars (3 reviews), ships from Amazon. | https://www.amazon.com/dp/B0F43QWVM3 | Source price | both | Checked Oct 10, 2026 | lite150 | main
p043 | Raspberry Pi 4 Model B | Electronics | 1 | 55 | 2 GB reference budget; actual memory variant/retailer may differ. | https://www.raspberrypi.com/products/raspberry-pi-4-model-b/ | Estimate | both |  | aps8072s mp80100 mp80100_220 c80100_220 | main
p045 | Waveshare 4 inch DPI LCD (C) | Electronics | 1 | 54.99 | 720 x 720 square capacitive display. | https://www.waveshare.com/product/4inch-dpi-lcd-c.htm | Source price | both | Checked Oct 2, 2026 | aps8072s mp80100 mp80100_220 c80100_220 | main
p046 | Teensy 4.0 | Electronics | 1 | 25 | Board allowance; use non-lockable reference. | https://www.pjrc.com/store/teensy40.html | Estimate | both |  | aps8072s mp80100 mp80100_220 c80100_220 | main
p048 | Waveshare SN65HVD230 CAN board | Electronics | 1 | 10.99 | 3.3 V CAN transceiver. | https://www.amazon.com/dp/B00KM6XMXO | Recorded price | both | Oct 2, 2026 | all | main
p049 | Pololu D42V55F5 regulator | Electronics | 1 | 39.95 | #5571, 5 V output, 60 V maximum input. | https://www.pololu.com/product/5571 | Source price | both | Checked Oct 2, 2026 | all | main
p050 | Noctua NF-A4x10 5V fan | Electronics | 1 | 17 | Non-PWM reference; unit allowance. | https://www.amazon.com/dp/B00NEMGCIA | Estimate | both |  | all | main
p052 | Right-angle micro-USB cable, pack | Electronics | 1 | 10 | Short setup/board cable. | https://www.amazon.com/dp/B08BZD66H4 | Estimate | both |  | aps8072s mp80100 mp80100_220 c80100_220 | main
p127 | Seeed XIAO ESP32-C3 | Electronics | 1 | 9.9 | Bluetooth link to the phone app and the knob; talks to the S1 over CAN through the CAN board. 4.7 stars (382), ships from Amazon. | https://www.amazon.com/dp/B0B94JZ2YF | Source price | both | Checked Oct 10, 2026 | lite150 | main
p128 | EC11 rotary encoders with push button and knob caps, 5-pack | Electronics | 1 | 9.99 | The resistance knob, through the left cover. 4.3 stars (163), ships from Amazon. Or the WWZMDiB 6-pack (B0C6Q67V97, $8.88). | https://www.amazon.com/dp/B08728K3YB | Source price | both | Checked Oct 10, 2026 | lite150 | main
p004 | USB isolator for controller setup | Accessories | 1 | 35 | Protects the PC when you set up the ODrive over USB. | https://shop.odriverobotics.com/ | Estimate | both |  | all | accessory
p026 | PTFE / lithium grease | Accessories | 1 | 10 | Lead screw and gears. | https://www.amazon.com/dp/B000XBH9HI | Estimate | both |  | all | accessory
p039 | Silicone wire, mixed gauges | Accessories | 1 | 45 | 10 to 24 AWG; lengths in the wiring reference. |  | Estimate | both |  | all | accessory
p040 | M5 ring terminals, pack | Accessories | 1 | 9.99 | 12–10 AWG terminals; verify selected listing. | https://www.amazon.com/dp/B0DM8FW4LV | Recorded price | both | Sep 2026 | aps8072s mp80100 mp80100_220 c80100_220 | accessory
p041 | Ferrules & heat-shrink | Accessories | 1 | 15 | Consumables allowance; crimping tools excluded. |  | Estimate | both |  | all | accessory
p129 | IEC C13 mains cord | Accessories | 1 | 8 | Any standard computer or monitor power cord. |  | Estimate | both |  | lite150 | accessory
p130 | 6.3 mm insulated female quick-disconnects | Accessories | 1 | 7 | For the inlet and rocker switch tabs. |  | Estimate | both |  | lite150 | accessory
p131 | Power supply mating connectors (CN1, CN2) | Accessories | 1 | 6 | The AC input and 12 V aux housings with crimps, as listed in the LOP-600 datasheet. |  | Estimate | both |  | lite150 | accessory
p132 | Ring terminals, M3.5 and M4, 10-16 AWG | Accessories | 1 | 8 | The supply's DC screws, its earth screw and the earth stud in the base plate. |  | Estimate | both |  | lite150 | accessory
p133 | Thermal pad, 0.5 mm, 6 W/mK | Accessories | 1 | 8 | Between the S1 and its plate. |  | Estimate | both |  | lite150 | accessory
p134 | JST GH 4-pin cable | Accessories | 1 | 7 | CAN from the CAN board to the S1. |  | Estimate | both |  | lite150 | accessory
p047 | Low-profile female header strips | Accessories | 1 | 8 | Teensy socket: 2 x 14-pin low-profile machined-pin female. | https://www.amazon.com/dp/B0948H7FPP | Estimate | both |  | all | accessory
p051 | Prototype perfboards, pack | Accessories | 1 | 10 | Three small boards (Teensy, CAN, regulator). | https://www.amazon.com/dp/B072Z7Y19F | Estimate | both |  | all | accessory
p044 | MicroSD card | Accessories | 1 | 10 | For the Raspberry Pi. |  | Estimate | both |  | aps8072s mp80100 mp80100_220 c80100_220 | accessory
p060 | PAHT-CF filament, 1 kg spool | Accessories | 2 | 60 | End pieces, level-wind, exit, tower, gears and brackets. | https://www.amazon.com/dp/B0F37YW223 | Estimate | cnc |  | all | accessory
p059 | PAHT-CF filament, 1 kg spool | Accessories | 4 | 60 | Printed build: the frame is printed too. | https://www.amazon.com/dp/B0F37YW223 | Estimate | printed |  | all | accessory
p108 | PETG-CF filament, 1 kg spool | Accessories | 1 | 30 | The covers. |  | Estimate | both |  | all | accessory
p061 | 1 mm EVA foam roll | Accessories | 1 | 10 | Battery pads: or print them in TPU 95A. | https://www.amazon.com/dp/B0BXJHVH5M | Estimate | both |  | aps8072s mp80100 mp80100_220 c80100_220 | accessory
p062 | 2 mm EVA foam sheet | Accessories | 1 | 10 | Battery pads: or print them in TPU 95A. | https://www.amazon.com/dp/B08YXYN327 | Estimate | both |  | aps8072s mp80100 mp80100_220 c80100_220 | accessory
p063 | Cable ties & thread locker | Accessories | 1 | 12 | Assembly consumables allowance. |  | Estimate | both |  | all | accessory
p064 | 1 inch steel rack hitch pin | Accessories | 1 | 20 | Or your rack's own 1 in pin: at least 92 mm between the head and the clip hole. | https://www.amazon.com/dp/B08974F734 | Estimate | both |  | all | accessory
p065 | Straight bar & carabiner | Accessories | 1 | 35 | Training attachment allowance; rack itself excluded. |  | Estimate | both |  | all | accessory
p066 | Metric socket screw assortment | Accessories | 1 | 22.99 | Purchase pack; exact installed sizes/counts are in the hardware manifest. | https://www.amazon.com/dp/B0FJFVG31G | Recorded price | both | Oct 2, 2026 | all | accessory
p067 | M4 button-head assortment | Accessories | 1 | 9.59 | Purchase pack; exact installed sizes/counts are in the hardware manifest. | https://www.amazon.com/dp/B0BJQ4M7D5 | Recorded price | both | Oct 2, 2026 | all | accessory
p072 | M2/M3/M4/M5 heat-set insert kit | Accessories | 1 | 25 | Purchase pack; exact installed sizes/counts are in the hardware manifest. | https://www.amazon.com/dp/B08K1BVGN9 | Estimate | both |  | all | accessory
p073 | M2.5 heat-set inserts, pack | Accessories | 1 | 10 | Purchase pack; exact installed sizes/counts are in the hardware manifest. | https://www.amazon.com/dp/B0CS6YVJYD | Estimate | both |  | all | accessory
p074 | M3 flat-head assortment | Accessories | 1 | 15 | Purchase pack; exact installed sizes/counts are in the hardware manifest. | https://www.amazon.com/dp/B0GS8FZLTK | Estimate | both |  | all | accessory
p075 | M3 x 25 flat-head screws, pack | Accessories | 1 | 8 | Purchase pack; exact installed sizes/counts are in the hardware manifest. | https://www.amazon.com/dp/B0H5JVF4K4 | Estimate | both |  | all | accessory
p076 | M4 x 10 flat-head screws, pack | Accessories | 1 | 8 | Purchase pack; exact installed sizes/counts are in the hardware manifest. | https://www.amazon.com/dp/B0956VQVJ2 | Estimate | both |  | all | accessory
p077 | M4 flat-head assortment | Accessories | 1 | 12 | Purchase pack; exact installed sizes/counts are in the hardware manifest. | https://www.amazon.com/dp/B0CW5Y4RQY | Estimate | both |  | all | accessory
p078 | M2.5 x 5 flat-head screws, pack | Accessories | 1 | 8 | Purchase pack; exact installed sizes/counts are in the hardware manifest. | https://www.amazon.com/dp/B0CG1NVX6J | Estimate | both |  | all | accessory
p079 | M2.5 socket screw assortment | Accessories | 1 | 12 | Purchase pack; exact installed sizes/counts are in the hardware manifest. | https://www.amazon.com/dp/B0FG2BYJSR | Estimate | both |  | all | accessory
p080 | M2.5 x 5 socket screws, pack | Accessories | 1 | 8 | Purchase pack; exact installed sizes/counts are in the hardware manifest. | https://www.amazon.com/dp/B0GM84W3X8 | Estimate | both |  | all | accessory
p109 | M3 x 40 countersunk screws, pack | Accessories | 1 | 8 | Exit clamp, 4 needed. |  | Estimate | both |  | all | accessory
p110 | M3 x 10 low-head socket screws (DIN 7984), pack | Accessories | 1 | 7 | Lead screw nut flange, 4 needed. |  | Estimate | both |  | all | accessory
p085 | M6 x 16 countersunk screws, pack | Accessories | 1 | 8 | Rack mount: M6 x 22 (4) and M6 x 30 (2). |  | Estimate | both |  | all | accessory
p111 | M10 nyloc nuts and washers | Accessories | 1 | 6 | Exit pulley axles, 2 of each. |  | Estimate | both |  | all | accessory
p083 | Lock-nut & washer assortment | Accessories | 1 | 12 | Purchase pack; exact installed sizes/counts are in the hardware manifest. | https://www.amazon.com/dp/B0F1FGKC1C | Estimate | both |  | all | accessory
p084 | Plain hex-nut assortment | Accessories | 1 | 9 | Purchase pack; exact installed sizes/counts are in the hardware manifest. | https://www.amazon.com/dp/B097N3SGCD | Estimate | both |  | all | accessory
p102 | Laser-cut 6061-T6 plates, 0.250 in | Fabrication | 1 | 220 | Only if you have the plates cut: instant-priced online order (e.g. SendCutSend), tapped and countersunk as drawn. You weld the frame, rack mount and drum. | https://sendcutsend.com | Estimate | cnc |  | all | if outsourced
p103 | Drum tube, 6061, 1-1/4 in OD x 0.250 in wall, 100 mm | Fabrication | 1 | 15 | Only if you buy the tube: cut to length, ask for T6. | https://www.amazon.com/dp/B0BFGLLHXC | Estimate | cnc |  | all | if outsourced
p054 | Bearing cheeks, four cut plates | Fabrication | 1 | 30 | 2 mm steel, in the same laser order. |  | Estimate | both |  | all | if outsourced

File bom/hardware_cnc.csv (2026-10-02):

part | group | kind | size | source | note
B_V3_ODrive_PCB_supplier_810 | electronics | fastener | B_V3_ODrive_PCB_supplier_810 |  | V21: real helical nominal thread surfaces; verify purchased fastener class/engagement.
B_V3_ODrive_PCB_supplier_811 | electronics | fastener | B_V3_ODrive_PCB_supplier_811 |  | V21: real helical nominal thread surfaces; verify purchased fastener class/engagement.
B_V3_ODrive_PCB_supplier_814 | electronics | fastener | B_V3_ODrive_PCB_supplier_814 |  | V21: real helical nominal thread surfaces; verify purchased fastener class/engagement.
B_V3_ODrive_PCB_supplier_817 | electronics | fastener | B_V3_ODrive_PCB_supplier_817 |  | V21: real helical nominal thread surfaces; verify purchased fastener class/engagement.
B_V21_goBILDA_1301_0016_0012_left | drivetrain | fastener | B_V21_goBILDA_1301_0016_0012_left |  | Supplier STEP. FOUR MOUNTING HOLES DRILLED4.4mm CLEARANCE for screws into drum inserts; pinch thread retained. Original supplier STEP archived unchanged.
I_V21_hub_left_1 | drivetrain | fastener | I_V21_hub_left_1 |  | Match pocket to actual insert supplier; coupon test required. V21: real helical nominal thread surfaces; verify purchased fastener class/engagement.
B_V21_hub_left_1 | drivetrain | fastener | B_V21_hub_left_1 |  | V21: real helical nominal thread surfaces; verify purchased fastener class/engagement.
I_V21_hub_left_2 | drivetrain | fastener | I_V21_hub_left_2 |  | Match pocket to actual insert supplier; coupon test required. V21: real helical nominal thread surfaces; verify purchased fastener class/engagement.
B_V21_hub_left_2 | drivetrain | fastener | B_V21_hub_left_2 |  | V21: real helical nominal thread surfaces; verify purchased fastener class/engagement.
I_V21_hub_left_3 | drivetrain | fastener | I_V21_hub_left_3 |  | Match pocket to actual insert supplier; coupon test required. V21: real helical nominal thread surfaces; verify purchased fastener class/engagement.
B_V21_hub_left_3 | drivetrain | fastener | B_V21_hub_left_3 |  | V21: real helical nominal thread surfaces; verify purchased fastener class/engagement.
I_V21_hub_left_4 | drivetrain | fastener | I_V21_hub_left_4 |  | Match pocket to actual insert supplier; coupon test required. V21: real helical nominal thread surfaces; verify purchased fastener class/engagement.
B_V21_hub_left_4 | drivetrain | fastener | B_V21_hub_left_4 |  | V21: real helical nominal thread surfaces; verify purchased fastener class/engagement.
I_V30_anchor_1_M4x4 | drivetrain | fastener | I_V30_anchor_1_M4x4 |  | V37 nominal M4 insert X86.25..90.25, installed from open drum face before plate; 2.1mm closed flange floor; actual insert and pullout test pending.
I_V30_anchor_2_M4x4 | drivetrain | fastener | I_V30_anchor_2_M4x4 |  | V37 nominal M4 insert X86.25..90.25, installed from open drum face before plate; 2.1mm closed flange floor; actual insert and pullout test pending.
I_V30_anchor_3_M4x4 | drivetrain | fastener | I_V30_anchor_3_M4x4 |  | V37 nominal M4 insert X86.25..90.25, installed from open drum face before plate; 2.1mm closed flange floor; actual insert and pullout test pending.
B_V37_anchor_1_M4x8_button | drivetrain | fastener | B_V37_anchor_1_M4x8_button |  | Nominal head envelope D7.6 H2.2; simplified thread. Flat underside bears on 2mm plate; 4mm insert engagement, 1.4mm tip clearance.
B_V37_anchor_2_M4x8_button | drivetrain | fastener | B_V37_anchor_2_M4x8_button |  | Nominal head envelope D7.6 H2.2; simplified thread. Flat underside bears on 2mm plate; 4mm insert engagement, 1.4mm tip clearance.
B_V37_anchor_3_M4x8_button | drivetrain | fastener | B_V37_anchor_3_M4x8_button |  | Nominal head envelope D7.6 H2.2; simplified thread. Flat underside bears on 2mm plate; 4mm insert engagement, 1.4mm tip clearance.
V43_REF_motor_spacer_0 | drivetrain | spacer | V43_REF_motor_spacer_0 |  | Standard M5 ID, 3 mm spacer. Actual motor thread depth must be measured.
V43_B_motor_0 | drivetrain | fastener | V43_B_motor_0 |  | M5x12 socket screw through plate/spacer; nominal 5 mm motor engagement, confirm actual motor blind-hole depth.
V43_REF_motor_spacer_1 | drivetrain | spacer | V43_REF_motor_spacer_1 |  | Standard M5 ID, 3 mm spacer. Actual motor thread depth must be measured.
V43_B_motor_1 | drivetrain | fastener | V43_B_motor_1 |  | M5x12 socket screw through plate/spacer; nominal 5 mm motor engagement, confirm actual motor blind-hole depth.
V43_REF_motor_spacer_2 | drivetrain | spacer | V43_REF_motor_spacer_2 |  | Standard M5 ID, 3 mm spacer. Actual motor thread depth must be measured.
V43_B_motor_2 | drivetrain | fastener | V43_B_motor_2 |  | M5x12 socket screw through plate/spacer; nominal 5 mm motor engagement, confirm actual motor blind-hole depth.
V43_REF_motor_spacer_3 | drivetrain | spacer | V43_REF_motor_spacer_3 |  | Standard M5 ID, 3 mm spacer. Actual motor thread depth must be measured.
V43_B_motor_3 | drivetrain | fastener | V43_B_motor_3 |  | M5x12 socket screw through plate/spacer; nominal 5 mm motor engagement, confirm actual motor blind-hole depth.
V43_B_motor_web_-101_16 | drivetrain | fastener | V43_B_motor_web_-101_16 |  | M4x20 button screw. Fasten plate to braces before installing motor. Rear nut socket enters through open brace center; front Allen access requires motor removal.
V43_W_head_motor_web_-101_16 | drivetrain | fastener | V43_W_head_motor_web_-101_16 |  | Standard M4 washer under screw head.
V43_W_nut_motor_web_-101_16 | drivetrain | fastener | V43_W_nut_motor_web_-101_16 |  | Standard M4 washer under exposed nut.
V43_N_motor_web_-101_16 | drivetrain | fastener | V43_N_motor_web_-101_16 |  | Standard M4 hex nut; no insert or enclosed nut pocket.
V43_B_motor_web_-101_30 | drivetrain | fastener | V43_B_motor_web_-101_30 |  | M4x20 button screw. Fasten plate to braces before installing motor. Rear nut socket enters through open brace center; front Allen access requires motor removal.
V43_W_head_motor_web_-101_30 | drivetrain | fastener | V43_W_head_motor_web_-101_30 |  | Standard M4 washer under screw head.
V43_W_nut_motor_web_-101_30 | drivetrain | fastener | V43_W_nut_motor_web_-101_30 |  | Standard M4 washer under exposed nut.
V43_N_motor_web_-101_30 | drivetrain | fastener | V43_N_motor_web_-101_30 |  | Standard M4 hex nut; no insert or enclosed nut pocket.
V43_B_motor_foot_-101 | drivetrain | fastener | V43_B_motor_foot_-101 |  | M4x16 socket screw. Top Allen access between ribs; exposed nut below chassis.
V43_W_head_motor_foot_-101 | drivetrain | fastener | V43_W_head_motor_foot_-101 |  | Standard M4 washer under screw head.
V43_B_motor_web_-24_16 | drivetrain | fastener | V43_B_motor_web_-24_16 |  | M4x20 button screw. Fasten plate to braces before installing motor. Rear nut socket enters through open brace center; front Allen access requires motor removal.
V43_W_head_motor_web_-24_16 | drivetrain | fastener | V43_W_head_motor_web_-24_16 |  | Standard M4 washer under screw head. Rectangular trial: rear motor brace/joint shifted 6 mm inward.
V43_W_nut_motor_web_-24_16 | drivetrain | fastener | V43_W_nut_motor_web_-24_16 |  | Standard M4 washer under exposed nut. Rectangular trial: rear motor brace/joint shifted 6 mm inward.
V43_N_motor_web_-24_16 | drivetrain | fastener | V43_N_motor_web_-24_16 |  | Standard M4 hex nut; no insert or enclosed nut pocket. Rectangular trial: rear motor brace/joint shifted 6 mm inward.
V43_B_motor_web_-24_30 | drivetrain | fastener | V43_B_motor_web_-24_30 |  | M4x20 button screw. Fasten plate to braces before installing motor. Rear nut socket enters through open brace center; front Allen access requires motor removal.
V43_W_head_motor_web_-24_30 | drivetrain | fastener | V43_W_head_motor_web_-24_30 |  | Standard M4 washer under screw head. Rectangular trial: rear motor brace/joint shifted 6 mm inward.
V43_W_nut_motor_web_-24_30 | drivetrain | fastener | V43_W_nut_motor_web_-24_30 |  | Standard M4 washer under exposed nut. Rectangular trial: rear motor brace/joint shifted 6 mm inward.
V43_N_motor_web_-24_30 | drivetrain | fastener | V43_N_motor_web_-24_30 |  | Standard M4 hex nut; no insert or enclosed nut pocket. Rectangular trial: rear motor brace/joint shifted 6 mm inward.
V43_B_motor_foot_-24 | drivetrain | fastener | V43_B_motor_foot_-24 |  | M4x16 socket screw. Top Allen access between ribs; exposed nut below chassis. Rectangular trial: rear motor brace/joint shifted 6 mm inward.
V43_W_head_motor_foot_-24 | drivetrain | fastener | V43_W_head_motor_foot_-24 |  | Standard M4 washer under screw head. Rectangular trial: rear motor brace/joint shifted 6 mm inward.
V43_B_retainer_left_-83.5_FM6 | drivetrain | fastener | V43_B_retainer_left_-83.5_FM6 |  | M3x16 socket screw across 12.4 mm cheek/cartridge stack and 2.4 mm nut; 1.2 mm tip beyond nut. Shortened to clear adjacent foot-screw insertion. Moved +5 mm tow
V43_N_retainer_left_-83.5_FM6 | drivetrain | fastener | V43_N_retainer_left_-83.5_FM6 |  | Standard M3 nut, exposed tool access. Moved +5 mm toward the drum (fairlead module rev 6).
V43_B_retainer_left_-41.5_FM6 | drivetrain | fastener | V43_B_retainer_left_-41.5_FM6 |  | M3x16 socket screw across 12.4 mm cheek/cartridge stack and 2.4 mm nut; 1.2 mm tip beyond nut. Shortened to clear adjacent foot-screw insertion. Moved +5 mm tow
V43_N_retainer_left_-41.5_FM6 | drivetrain | fastener | V43_N_retainer_left_-41.5_FM6 |  | Standard M3 nut, exposed tool access. Moved +5 mm toward the drum (fairlead module rev 6).
V43_B_bearing_foot_left_-14_-82.5_FM6 | drivetrain | fastener | V43_B_bearing_foot_left_-14_-82.5_FM6 |  | M4x16 socket screw. Install with underside chassis access before fitting the drum/shaft. Nuts remain exposed below the plate. Moved +5 mm toward the drum (fairl
V43_W_head_bearing_foot_left_-14_-82.5_FM6 | drivetrain | fastener | V43_W_head_bearing_foot_left_-14_-82.5_FM6 |  | Standard M4 washer under screw head. Moved +5 mm toward the drum (fairlead module rev 6).
V43_B_bearing_foot_left_-14_-42.5_FM6 | drivetrain | fastener | V43_B_bearing_foot_left_-14_-42.5_FM6 |  | M4x16 socket screw. Install with underside chassis access before fitting the drum/shaft. Nuts remain exposed below the plate. Moved +5 mm toward the drum (fairl
V43_W_head_bearing_foot_left_-14_-42.5_FM6 | drivetrain | fastener | V43_W_head_bearing_foot_left_-14_-42.5_FM6 |  | Standard M4 washer under screw head. Moved +5 mm toward the drum (fairlead module rev 6).
V43_B_bearing_foot_left_14_-82.5_FM6 | drivetrain | fastener | V43_B_bearing_foot_left_14_-82.5_FM6 |  | M4x16 socket screw. Install with underside chassis access before fitting the drum/shaft. Nuts remain exposed below the plate. Moved +5 mm toward the drum (fairl
V43_W_head_bearing_foot_left_14_-82.5_FM6 | drivetrain | fastener | V43_W_head_bearing_foot_left_14_-82.5_FM6 |  | Standard M4 washer under screw head. Moved +5 mm toward the drum (fairlead module rev 6).
V43_B_bearing_foot_left_14_-42.5_FM6 | drivetrain | fastener | V43_B_bearing_foot_left_14_-42.5_FM6 |  | M4x16 socket screw. Install with underside chassis access before fitting the drum/shaft. Nuts remain exposed below the plate. Moved +5 mm toward the drum (fairl
V43_W_head_bearing_foot_left_14_-42.5_FM6 | drivetrain | fastener | V43_W_head_bearing_foot_left_14_-42.5_FM6 |  | Standard M4 washer under screw head. Moved +5 mm toward the drum (fairlead module rev 6).
B_V21_goBILDA_1301_0016_0012_right_FM9 | drivetrain | fastener | B_V21_goBILDA_1301_0016_0012_right_FM9 |  | Supplier STEP. FOUR MOUNTING HOLES DRILLED4.4mm CLEARANCE for screws into drum inserts; pinch thread retained. Original supplier STEP archived unchanged. Moved
I_V21_hub_right_1_FM9 | drivetrain | fastener | I_V21_hub_right_1_FM9 |  | Match pocket to actual insert supplier; coupon test required. V21: real helical nominal thread surfaces; verify purchased fastener class/engagement. Moved +6 mm
B_V21_hub_right_1_FM9 | drivetrain | fastener | B_V21_hub_right_1_FM9 |  | V21: real helical nominal thread surfaces; verify purchased fastener class/engagement. Moved +6 mm with the 6 mm wider drum (fairlead rev 9).
I_V21_hub_right_2_FM9 | drivetrain | fastener | I_V21_hub_right_2_FM9 |  | Match pocket to actual insert supplier; coupon test required. V21: real helical nominal thread surfaces; verify purchased fastener class/engagement. Moved +6 mm
B_V21_hub_right_2_FM9 | drivetrain | fastener | B_V21_hub_right_2_FM9 |  | V21: real helical nominal thread surfaces; verify purchased fastener class/engagement. Moved +6 mm with the 6 mm wider drum (fairlead rev 9).
I_V21_hub_right_3_FM9 | drivetrain | fastener | I_V21_hub_right_3_FM9 |  | Match pocket to actual insert supplier; coupon test required. V21: real helical nominal thread surfaces; verify purchased fastener class/engagement. Moved +6 mm
B_V21_hub_right_3_FM9 | drivetrain | fastener | B_V21_hub_right_3_FM9 |  | V21: real helical nominal thread surfaces; verify purchased fastener class/engagement. Moved +6 mm with the 6 mm wider drum (fairlead rev 9).
I_V21_hub_right_4_FM9 | drivetrain | fastener | I_V21_hub_right_4_FM9 |  | Match pocket to actual insert supplier; coupon test required. V21: real helical nominal thread surfaces; verify purchased fastener class/engagement. Moved +6 mm
B_V21_hub_right_4_FM9 | drivetrain | fastener | B_V21_hub_right_4_FM9 |  | V21: real helical nominal thread surfaces; verify purchased fastener class/engagement. Moved +6 mm with the 6 mm wider drum (fairlead rev 9).
V43_B_retainer_right_-83.5_FM9 | drivetrain | fastener | V43_B_retainer_right_-83.5_FM9 |  | M3x16 socket screw across 12.4 mm cheek/cartridge stack and 2.4 mm nut; 1.2 mm tip beyond nut. Shortened to clear adjacent foot-screw insertion. Moved -5 mm tow
V43_N_retainer_right_-83.5_FM9 | drivetrain | fastener | V43_N_retainer_right_-83.5_FM9 |  | Standard M3 nut, exposed tool access. Moved -5 mm toward the drum (fairlead module rev 6). Moved +6 mm with the 6 mm wider drum (fairlead rev 9).
V43_B_retainer_right_-41.5_FM9 | drivetrain | fastener | V43_B_retainer_right_-41.5_FM9 |  | M3x16 socket screw across 12.4 mm cheek/cartridge stack and 2.4 mm nut; 1.2 mm tip beyond nut. Shortened to clear adjacent foot-screw insertion. Moved -5 mm tow
V43_N_retainer_right_-41.5_FM9 | drivetrain | fastener | V43_N_retainer_right_-41.5_FM9 |  | Standard M3 nut, exposed tool access. Moved -5 mm toward the drum (fairlead module rev 6). Moved +6 mm with the 6 mm wider drum (fairlead rev 9).
V43_B_bearing_foot_right_-14_-82.5_FM9 | drivetrain | fastener | V43_B_bearing_foot_right_-14_-82.5_FM9 |  | M4x16 socket screw. Install with underside chassis access before fitting the drum/shaft. Nuts remain exposed below the plate. Moved -5 mm toward the drum (fairl
V43_W_head_bearing_foot_right_-14_-82.5_FM9 | drivetrain | fastener | V43_W_head_bearing_foot_right_-14_-82.5_FM9 |  | Standard M4 washer under screw head. Moved -5 mm toward the drum (fairlead module rev 6). Moved +6 mm with the 6 mm wider drum (fairlead rev 9).
V43_B_bearing_foot_right_-14_-42.5_FM9 | drivetrain | fastener | V43_B_bearing_foot_right_-14_-42.5_FM9 |  | M4x16 socket screw. Install with underside chassis access before fitting the drum/shaft. Nuts remain exposed below the plate. Moved -5 mm toward the drum (fairl
V43_W_head_bearing_foot_right_-14_-42.5_FM9 | drivetrain | fastener | V43_W_head_bearing_foot_right_-14_-42.5_FM9 |  | Standard M4 washer under screw head. Moved -5 mm toward the drum (fairlead module rev 6). Moved +6 mm with the 6 mm wider drum (fairlead rev 9).
V43_B_bearing_foot_right_14_-82.5_FM9 | drivetrain | fastener | V43_B_bearing_foot_right_14_-82.5_FM9 |  | M4x16 socket screw. Install with underside chassis access before fitting the drum/shaft. Nuts remain exposed below the plate. Moved -5 mm toward the drum (fairl
V43_W_head_bearing_foot_right_14_-82.5_FM9 | drivetrain | fastener | V43_W_head_bearing_foot_right_14_-82.5_FM9 |  | Standard M4 washer under screw head. Moved -5 mm toward the drum (fairlead module rev 6). Moved +6 mm with the 6 mm wider drum (fairlead rev 9).
V43_B_bearing_foot_right_14_-42.5_FM9 | drivetrain | fastener | V43_B_bearing_foot_right_14_-42.5_FM9 |  | M4x16 socket screw. Install with underside chassis access before fitting the drum/shaft. Nuts remain exposed below the plate. Moved -5 mm toward the drum (fairl
V43_W_head_bearing_foot_right_14_-42.5_FM9 | drivetrain | fastener | V43_W_head_bearing_foot_right_14_-42.5_FM9 |  | Standard M4 washer under screw head. Moved -5 mm toward the drum (fairlead module rev 6). Moved +6 mm with the 6 mm wider drum (fairlead rev 9).
FM10_Carrier_M3x25_1 | fairlead | fastener | FM10 Carrier_M3x25_1 |  | Actual saved oval-exit assembly, unchanged internal spacing; translated with main carrier bearing. Whole exit shifted inward; internal spacings unchanged. Exis
FM10_Carrier_M3x25_2 | fairlead | fastener | FM10 Carrier_M3x25_2 |  | Actual saved oval-exit assembly, unchanged internal spacing; translated with main carrier bearing. Whole exit shifted inward; internal spacings unchanged. Exis
FM10_Carrier_M3x25_3 | fairlead | fastener | FM10 Carrier_M3x25_3 |  | Actual saved oval-exit assembly, unchanged internal spacing; translated with main carrier bearing. Whole exit shifted inward; internal spacings unchanged. Exis
FM10_Carrier_M3x25_4 | fairlead | fastener | FM10 Carrier_M3x25_4 |  | Actual saved oval-exit assembly, unchanged internal spacing; translated with main carrier bearing. Whole exit shifted inward; internal spacings unchanged. Exis
FM10_Hub_retainer_M3x8_1 | fairlead | fastener | FM10 Hub_retainer_M3x8_1 |  | R14: countersunk M3 x 8 (ISO 10642), head flush in the rear inner-race retainer (was a hex head 3 mm proud); same nut.
FM10_Hub_retainer_M3_nut_1 | fairlead | fastener | FM10 Hub_retainer_M3_nut_1 |  | Actual saved oval-exit assembly, unchanged internal spacing; translated with main carrier bearing. Whole exit shifted inward; internal spacings unchanged. Exis
FM10_Hub_retainer_M3x8_2 | fairlead | fastener | FM10 Hub_retainer_M3x8_2 |  | R14: countersunk M3 x 8 (ISO 10642), head flush in the rear inner-race retainer (was a hex head 3 mm proud); same nut.
FM10_Hub_retainer_M3_nut_2 | fairlead | fastener | FM10 Hub_retainer_M3_nut_2 |  | Actual saved oval-exit assembly, unchanged internal spacing; translated with main carrier bearing. Whole exit shifted inward; internal spacings unchanged. Exis
FM10_Hub_retainer_M3x8_3 | fairlead | fastener | FM10 Hub_retainer_M3x8_3 |  | R14: countersunk M3 x 8 (ISO 10642), head flush in the rear inner-race retainer (was a hex head 3 mm proud); same nut.
FM10_Hub_retainer_M3_nut_3 | fairlead | fastener | FM10 Hub_retainer_M3_nut_3 |  | Actual saved oval-exit assembly, unchanged internal spacing; translated with main carrier bearing. Whole exit shifted inward; internal spacings unchanged. Exis
FM10_Oval_clamp_M3x14_-1_54 | fairlead | fastener | FM10 Oval_clamp_M3x14_-1_54 |  | Actual saved oval-exit assembly, unchanged internal spacing; translated with main carrier bearing. Nominal M3 x 14 socket screw, shortened for the ring movement
FM10_Oval_clamp_M3_nut_-1_54 | fairlead | fastener | FM10 Oval_clamp_M3_nut_-1_54 |  | Actual saved oval-exit assembly, unchanged internal spacing; translated with main carrier bearing. M3 nut in rear hex recess; install before placing cap. Whole
FM10_Oval_clamp_M3x14_-1_94 | fairlead | fastener | FM10 Oval_clamp_M3x14_-1_94 |  | Actual saved oval-exit assembly, unchanged internal spacing; translated with main carrier bearing. Nominal M3 x 14 socket screw, shortened for the ring movement
FM10_Oval_clamp_M3_nut_-1_94 | fairlead | fastener | FM10 Oval_clamp_M3_nut_-1_94 |  | Actual saved oval-exit assembly, unchanged internal spacing; translated with main carrier bearing. M3 nut in rear hex recess; install before placing cap. Whole
FM10_Oval_clamp_M3x14_1_54 | fairlead | fastener | FM10 Oval_clamp_M3x14_1_54 |  | Actual saved oval-exit assembly, unchanged internal spacing; translated with main carrier bearing. Nominal M3 x 14 socket screw, shortened for the ring movement
FM10_Oval_clamp_M3_nut_1_54 | fairlead | fastener | FM10 Oval_clamp_M3_nut_1_54 |  | Actual saved oval-exit assembly, unchanged internal spacing; translated with main carrier bearing. M3 nut in rear hex recess; install before placing cap. Whole
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

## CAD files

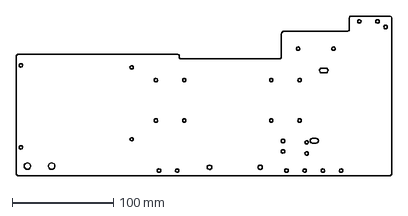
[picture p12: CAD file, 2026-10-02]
cad/dxf/S01_V44_CNC_bottom_plate_6061_5mm.dxf
371.0 x 157.5 mm

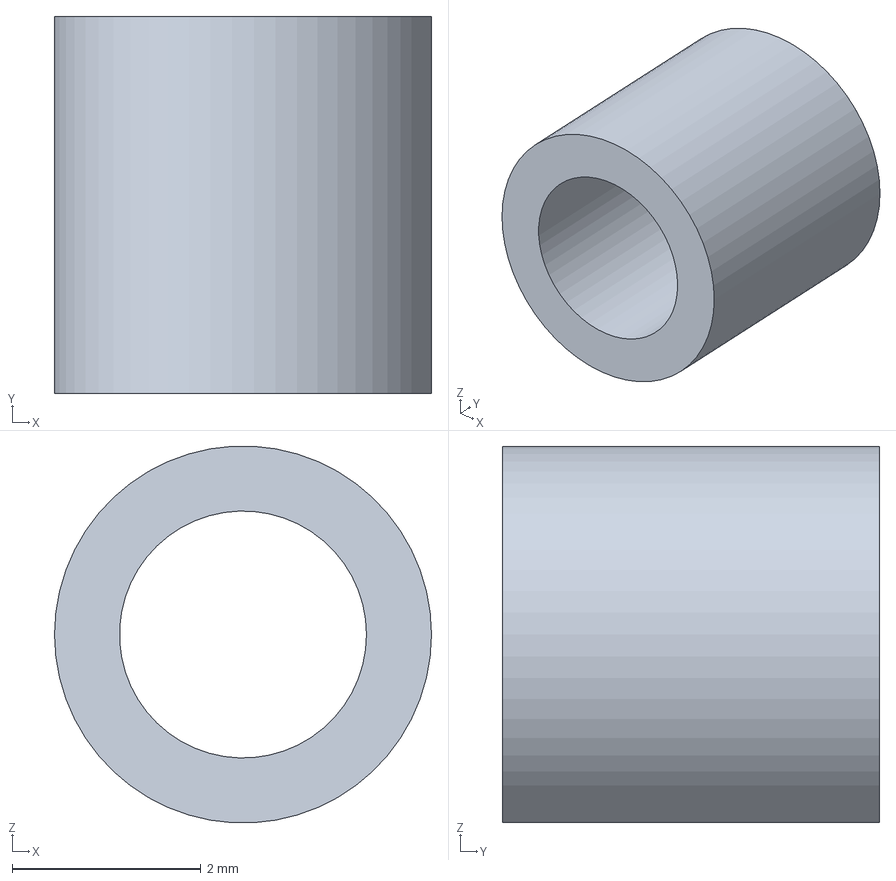
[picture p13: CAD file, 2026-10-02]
cad/step/cnc/F44_I_standoff_regulator_0_M2.5.step
4.00 x 4.00 x 3.99 mm

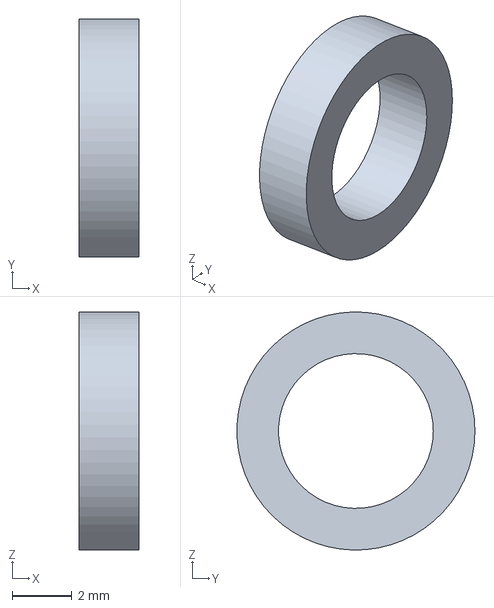
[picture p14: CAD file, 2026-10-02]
cad/step/printed/FM10_Exit_axle_M5_spacer_2mm_0_1.step
2.00 x 7.99 x 8.00 mm

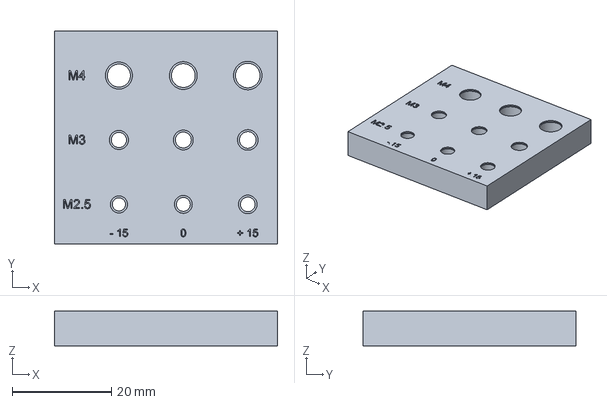
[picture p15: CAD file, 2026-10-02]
print/fit-coupons/01_inserts_M2.5_M3_M4.step
45.0 x 43.0 x 7.00 mm

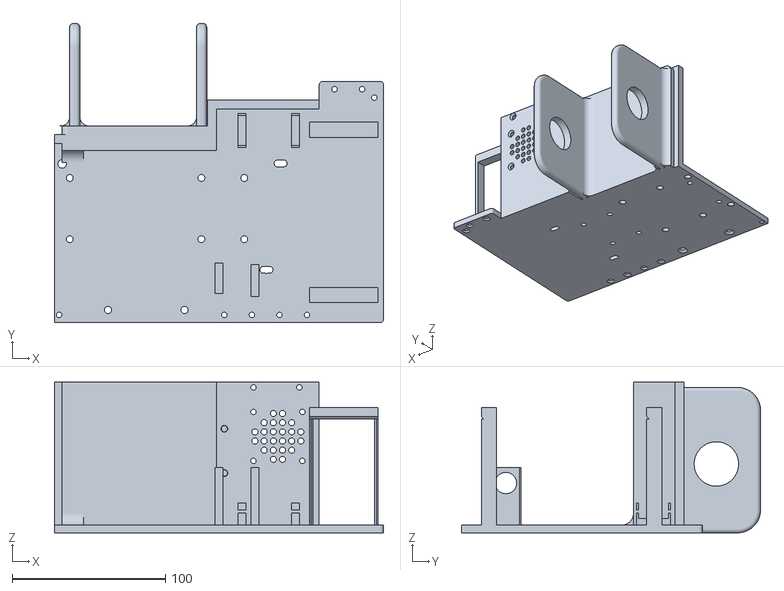
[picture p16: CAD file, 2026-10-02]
print/S01_V44_PRINT_bottom_plate_right.stl
215.0 x 195.5 x 98.4

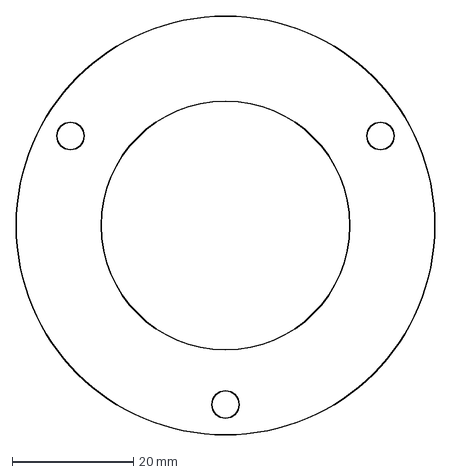
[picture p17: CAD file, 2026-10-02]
cad/dxf/V27_METAL_anchor_front.dxf
69.0 x 69.0 mm

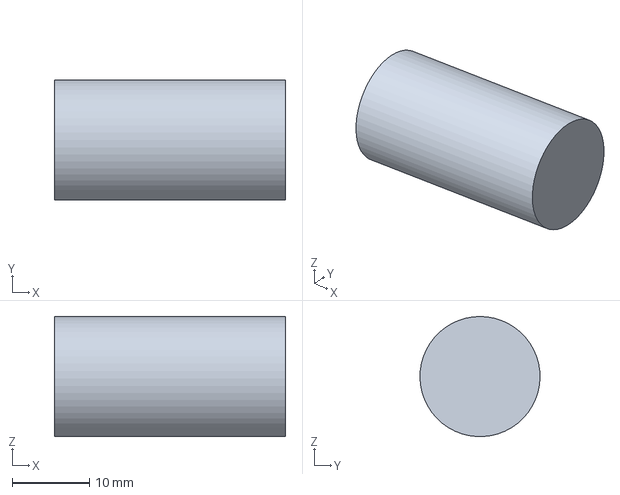
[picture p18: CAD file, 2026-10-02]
cad/step/cnc/KHK_SW0.8-R1_worm.step
30.0 x 15.6 x 15.6 mm

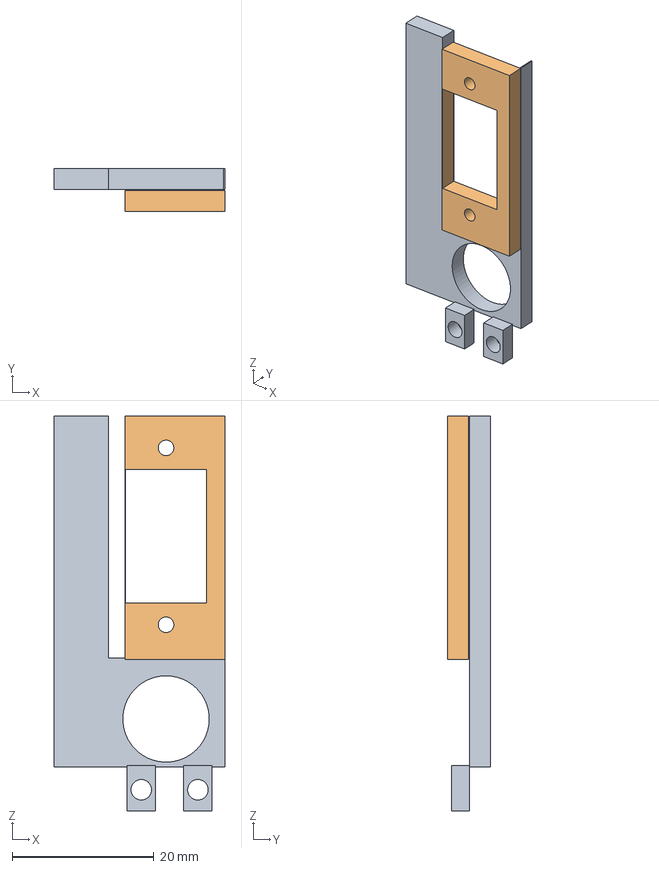
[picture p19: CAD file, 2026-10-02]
cad/step/printed/V44_PRINT_rear_IO_panel_flush.step
24.1 x 6.10 x 55.8 mm

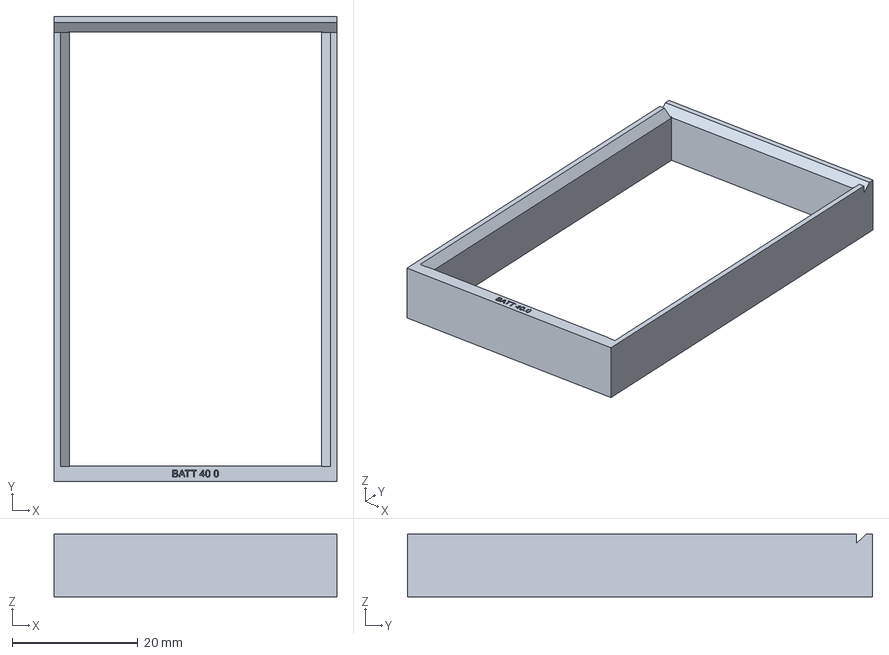
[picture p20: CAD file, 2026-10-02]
print/fit-coupons/03_battery_slide_slice.step
45.0 x 74.0 x 10.0 mm

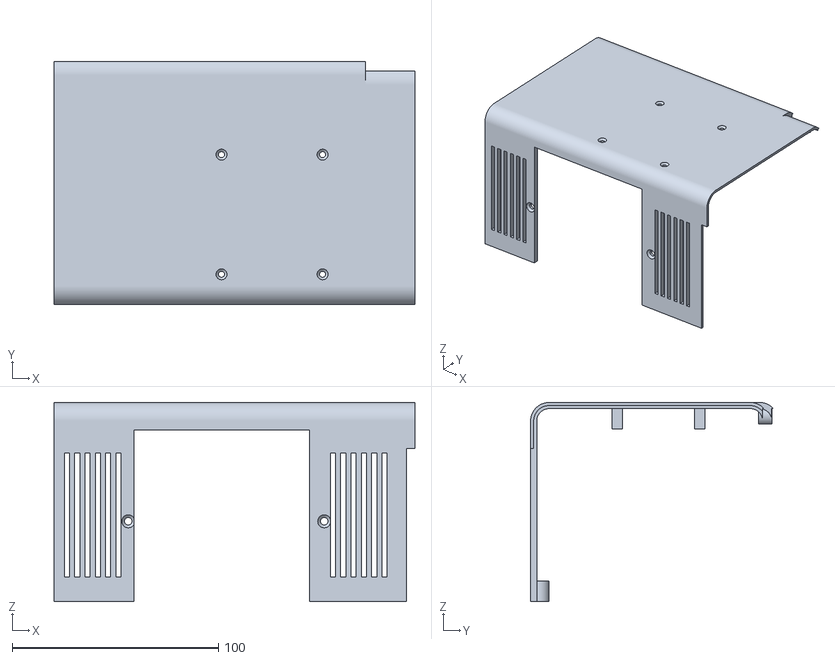
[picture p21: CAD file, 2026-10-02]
print/V44_PRINT_cover_left_screen.stl
175.0 x 117.7 x 96.5

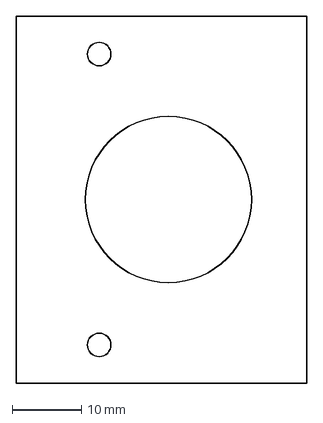
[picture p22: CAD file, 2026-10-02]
cad/dxf/V43_METAL_bearing_cheek_left_rear_FM6.dxf
42.0 x 53.0 mm

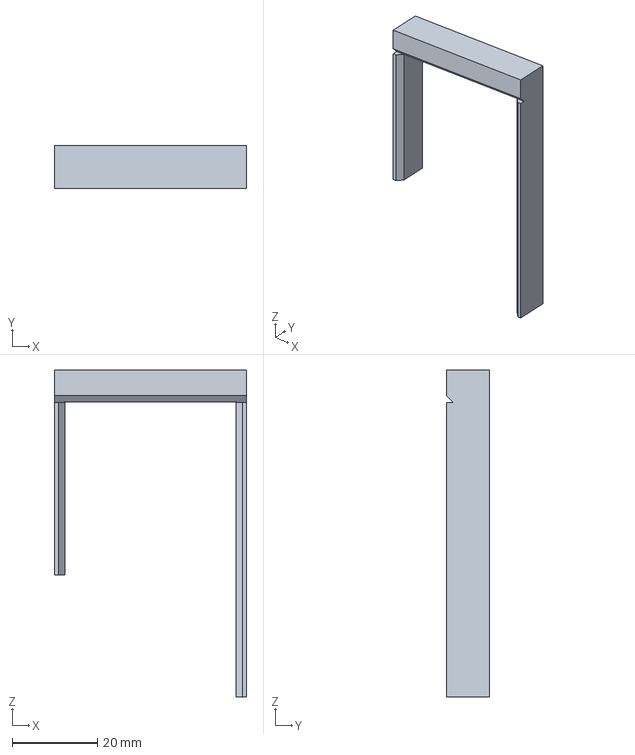
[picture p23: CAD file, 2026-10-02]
cad/step/cnc/MOUNT_battery_saddle_rear_printed_PA-CF.step
45.0 x 10.0 x 76.5 mm

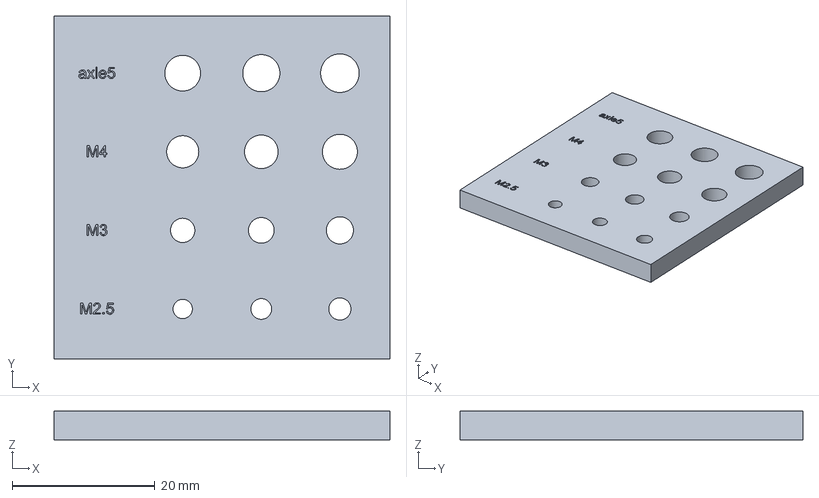
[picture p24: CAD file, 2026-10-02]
print/fit-coupons/02_clearance_holes.step
47.0 x 48.0 x 4.00 mm

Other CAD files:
cad/freecad/printed/V44_printed_assembly.FCStd
cad/freecad/cnc/V44_cnc_assembly.FCStd
cad/freecad/cnc/V44_cnc_drivetrain_motion.FCStd
cad/freecad/printed/V44_printed_drivetrain_motion.FCStd
cad/step/printed/F44_I_standoff_regulator_2_M2.5.step
cad/dxf/FM10_Front_outer_race_retainer_1mm.dxf
cad/dxf/FM10_Printed_oval_retaining_cap_-1.dxf
cad/dxf/FM10_Printed_oval_retaining_cap_1.dxf
cad/dxf/FM10_Rear_inner_race_retainer_2mm.dxf
cad/dxf/MOUNT_battery_hold-down_foam_2_mm_EVA.dxf
cad/dxf/MOUNT_battery_saddle_front_printed_PA-CF.dxf
cad/dxf/MOUNT_battery_saddle_rear_printed_PA-CF.dxf
cad/dxf/MOUNT_battery_separator_foam_2_mm_EVA.dxf
cad/dxf/MOUNT_fan_duct_mount_frame_printed.dxf
cad/dxf/MOUNT_front_board_plate_printed.dxf
cad/dxf/MOUNT_regulator_perfboard_standoffs.dxf
cad/dxf/MOUNT_screen_rear_retaining_frame_printed.dxf
cad/dxf/S17_V44_AL_flat_bar_front_1x0.25x12in.dxf
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

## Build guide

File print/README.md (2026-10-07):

# V44 print files (printed build)

28 files, exported from `print-v44/printed/` with every hole cut to its final size (inserts, clearance, pilots).
Print `../fit-coupons/` first in the same material and tune the hole sizes if needed. Sizes in mm (longest first);
bed: Bambu Lab P2S 256 mm. Parts are in the assembly frame: orient them in the slicer.

| File | Qty | Material | Size | Fits bed | Volume cm³ | Heat-set inserts | Face down |
|---|---:|---|---|---|---:|---|---|
| V43_PRINT_motor_gusset_-106.stl | 1 | PA-CF | 39 x 31 x 18 | yes | 8.4 | - | - |
| V43_PRINT_motor_gusset_-23.stl | 1 | PA-CF | 39 x 31 x 18 | yes | 8.3 | - | - |
| V43_PRINT_6001_cartridge_left_FM6.stl | 1 | PA-CF | 63 x 53 x 40 | yes | 25.7 | - | - |
| V43_PRINT_6001_cartridge_right_FM9.stl | 1 | PA-CF | 63 x 53 x 40 | yes | 25.7 | - | - |
| FM10_Fixed_bearing_housing.stl | 1 | PA-CF | 64 x 64 x 19 | yes | 20.0 | - | - |
| FM10_Front_outer_race_retainer_1mm.stl | 1 | PA-CF | 64 x 64 x 1 | yes | 1.3 | - | - |
| FM10_Rear_inner_race_retainer_2mm.stl | 1 | PA-CF | 43 x 43 x 2 | yes | 2.2 | - | - |
| FM10_Printed_oval_retaining_cap_-1.stl | 1 | PA-CF | 48 x 11 x 3 | yes | 0.9 | - | - |
| FM10_Printed_oval_retaining_cap_1.stl | 1 | PA-CF | 48 x 11 x 3 | yes | 0.9 | - | - |
| FM10_Printed_PA-CF_carrier_-_53T_m0.8_worm-wheel_ring_journal_sheave_fork.stl | 1 | PA-CF | 53 x 45 x 39 | yes | 23.8 | - | ring face down, supports under the fork |
| FM10_Square_back_plate_4-screw_enclosure_mount.stl | 1 | PA-CF | 74 x 70 x 40 | yes | 46.4 | 2 x M4 | back face down (6809 seat up) |
| FM10_Printed_oval_ring_carrier_filleted.stl | 1 | PA-CF | 60 x 43 x 33 | yes | 30.1 | - | - |
| MOUNT_ODrive_Pro_bracket_printed_PA-CF_base-mounted.stl | 1 | PA-CF | 78 x 76 x 18 | yes | 9.4 | 2 x M4 | - |
| MOUNT_fan_duct_mount_frame_printed.stl | 1 | PETG or PA-CF | 40 x 40 x 11 | yes | 5.5 | - | - |
| MOUNT_screen_rear_retaining_frame_printed.stl | 1 | PETG | 100 x 78 x 8 | yes | 5.8 | 2 x M3 | - |
| MOUNT_Teensy_perfboard_standoffs_0.stl | 2 | PETG | 8 x 5 x 5 | yes | 0.1 | - | - |
| MOUNT_CAN_board_perfboard_standoffs_0.stl | 4 | PETG | 6 x 5 x 5 | yes | 0.1 | - | - |
| MOUNT_regulator_perfboard_standoffs_0.stl | 4 | PETG | 7 x 5 x 5 | yes | 0.1 | - | - |
| MOUNT_front_board_plate_printed.stl | 1 | PETG | 78 x 39 x 8 | yes | 12.2 | 10 x M2.5, 2 x M3 | back face down |
| MOUNT_power_junction_bracket_printed.stl | 1 | PETG | 39 x 28 x 17 | yes | 3.0 | - | - |
| S01_V44_PRINT_bottom_plate_left.stl | 1 | PA-CF | 163 x 156 x 98 | yes | 199.5 | 10 x M4 | underside down |
| S01_V44_PRINT_bottom_plate_right.stl | 1 | PA-CF | 215 x 195 x 98 | yes | 443.0 | 2 x M3, 4 x M4 | underside down |
| V44_PRINT_cover_left_screen.stl | 1 | PETG-CF / PA-CF | 175 x 118 x 97 | yes | 82.0 | 5 x M3 | top down (wire loops bridge, no supports) |
| V44_PRINT_cover_centre_exit.stl | 1 | PETG-CF / PA-CF | 113 x 97 x 80 | yes | 30.8 | - | top down (wire loops bridge, no supports) |
| V44_PRINT_cover_right_grille.stl | 1 | PETG-CF / PA-CF | 158 x 108 x 97 | yes | 90.1 | 8 x M3 | top down (wire loops bridge, no supports) |
| V44_PRINT_end_cap_motor.stl | 1 | PETG-CF / PA-CF | 118 x 97 x 10 | yes | 30.6 | 2 x M3 | outer face down |
| V44_PRINT_end_cap_battery.stl | 1 | PETG-CF / PA-CF | 158 x 97 x 10 | yes | 52.3 | 1 x M3 | outer face down |
| V44_PRINT_rear_IO_panel_flush.stl | 1 | PETG-CF / PA-CF | 56 x 24 x 6 | yes | 2.5 | - | outer face down |

Total volume ≈ 1161 cm³ (solid; real use depends on infill).

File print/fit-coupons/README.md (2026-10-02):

# V44 print-fit coupons

1. inserts   - heat-set pockets (Ruthex RX) M2.5 3.6 / M3 4.0 / M4 5.6 at -0.15 / nominal / +0.15, depth L + 1, 0.5 mm lead-in.
               Press an insert into each; use the size that goes in straight and holds a torqued screw.
2. clearance - printed clearance holes M2.5 2.9 / M3 3.6 / M4 4.7 and the 5.2 pulley-axle hole, at -0.2 / nominal / +0.2.
               The screw (or the 5 mm shoulder) should slide through the nominal hole without forcing.
3. battery   - a 10 mm slice of the battery saddle tunnel (pack 39 + 0.5 per side = 40.0, 1.5 mm 45 deg lead-in, 1 mm foam
               gap on top). Slide a real TP2700 pack through it, both ways.
4. pulleys   - the exit pulley axle spacing: two 5.2 holes 21.13 mm apart in a plate with the carrier walls 11 mm apart.
               Fit the two U625ZZ on M5 shoulder bolts with 2 mm spacers and pull the cable through: it must run in both grooves.
5. seat6809  - the 6809 bearing seat of the square back plate (d58.0, 7 deep, 2 mm lip): the bearing should press in by hand.
Numbers match build_v44_fasteners.py (INSERTS / CLEAR), mounts-rev11/build_mounts.py (saddles) and the fairlead module (exit).

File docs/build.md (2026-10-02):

# Build instructions (printed variant)

Read `SAFETY.md` first. Order matters: some parts cannot be reached once others are in. Part names below match the files in
`print/`, `cad/step/` and the FreeCAD assembly (open `cad/freecad/printed/V44_printed_assembly.FCStd` alongside this page).

## 0. Before you start

1. Print the fit coupons (`print/fit-coupons/`) in your material and tune the insert and clearance holes (`printing.md`).
2. Print every part in `print/` (see `print/README.md` for material, orientation and the inserts each part takes).
3. Buy the parts in `bom/BOM.md`; cut nothing metal (the printed variant only drills the two aluminium flat bars).

## 1. Heat-set inserts

Press every brass insert (Ruthex RX, M2.5 / M3 / M4 x 4 mm) into its pocket with a soldering iron and an insert tip, square
to the face. `print/README.md` lists the inserts per part; the assembly shows each insert inside its part.

## 2. Base: bottom plate and flat bars

1. Drill the two 1 x 1/4 in aluminium flat bars (front and rear) at the countersunk holes of `S17_V44_AL_flat_bar_*`; countersink.
2. Join the two printed bottom-plate halves (`S01_V44_PRINT_bottom_plate_left` / `_right`, split at X 75) and screw the
   bars on from below: M4 x 10 countersunk into the plate inserts (14 joints, `bar_*` in the table below).

## 3. Drivetrain (motor end to gear end)

1. Motor face plate and gussets to the base; motor to the face plate (M5 into the motor, spacers per the model).
2. The two 6001 bearing cartridges (`V43_PRINT_6001_cartridge_*`) with their bearings, onto the base. **Bearing blocks go on
   before the drum.**
3. Drum assembly: drum, goBILDA hubs with their screws into the drum inserts, rope anchor. **The drum shaft slides in from the
   ODrive end** through both bearings and the drum hubs; coupling to the motor shaft.
4. Drum 60T gear and hub on the shaft end; encoder magnet in the shaft end.

## 4. Fairlead module

The fairlead (sheave, worm-wheel carrier, worm, shaft 2 and the exit swivel) is a module on the square back plate:
1. 6809 bearing into the back plate; the printed carrier's journal into it; sheave and rope-turn roller on their axles.
2. Worm shaft (6 mm D) with the KHK worm and its 20T gear on two flanged bearings; shaft 2 (8 mm REX) with its 60T and 20T on the
   printed pedestals (printed into the right bottom plate on this variant).
3. Exit swivel: housing with two 6808 bearings, the oval ring carrier with the two U625ZZ pulleys, retainers and the
   countersunk hub screws; housing onto the back-plate face (4 x M3 into inserts).
4. Module onto the base (2 x M4 from below). Check that the 60T gears mesh at 48 mm centres and the carrier turns freely
   +-45 deg by hand (it stops at +-48.4 deg).

## 5. Electronics

1. **Shaft 2 and the ODrive go in before the battery.** ODrive Pro on its printed bracket (heat spreader on 4 x M4 x 16, nuts in
   the bracket pockets); fan and duct on the rear wall.
2. Front board plate with the regulator, Teensy and CAN perfboards. **Screw the Teensy perfboard down before plugging the
   Teensy into its sockets** (the two screws sit under it).
3. Main fuse holder: **fuse cradles before the holder** (printed in on this variant); WAGO on its junction bracket.
4. Battery packs into the saddles (they slide in from the front, 1 mm foam on top); BMS on the right cover ceiling;
   Raspberry Pi on the left cover ceiling.

## 6. Wiring

Follow `wiring.md`. Thread the harness through the wire loops under the cover tops before fitting the far connectors.

## 7. Rope

Wind 3 dead wraps by hand at the anchor end, then wind the rope on under light tension through the sheave, roller and exit.
Set the payout window before the first loaded pull (`firmware-setup.md`).

## 8. Covers

Covers and end caps stand on the bottom plate: M3 from below into the foot bosses, and M3 countersunk from the back into the
rear wall. Rear I/O panel last (2 tabs, M2.5).

## Fasteners by joint

Generated from the model (`fasteners-report.json`): every screw, the parts it passes through and what it engages.

| Joint | Screw | Through / into | Note |
|---|---|---|---|
| bar_0 | M4x10 csk | S17_V44_AL_flat_bar_front_1x0.25x12in -> S01_V44_PRINT_bottom_plate_left | Flat bar to the printed bottom plate: M4 countersunk up through the bar into a heat-set insert. |
| bar_1 | M4x10 csk | S17_V44_AL_flat_bar_rear_1x0.25x12in -> S01_V44_PRINT_bottom_plate_left | Flat bar to the printed bottom plate: M4 countersunk up through the bar into a heat-set insert. |
| bar_2 | M4x10 csk | S17_V44_AL_flat_bar_front_1x0.25x12in -> S01_V44_PRINT_bottom_plate_left | Flat bar to the printed bottom plate: M4 countersunk up through the bar into a heat-set insert. |
| bar_3 | M4x10 csk | S17_V44_AL_flat_bar_rear_1x0.25x12in -> S01_V44_PRINT_bottom_plate_left | Flat bar to the printed bottom plate: M4 countersunk up through the bar into a heat-set insert. |
| bar_4 | M4x10 csk | S17_V44_AL_flat_bar_front_1x0.25x12in -> S01_V44_PRINT_bottom_plate_left | Flat bar to the printed bottom plate: M4 countersunk up through the bar into a heat-set insert. |
| bar_5 | M4x10 csk | S17_V44_AL_flat_bar_rear_1x0.25x12in -> S01_V44_PRINT_bottom_plate_left | Flat bar to the printed bottom plate: M4 countersunk up through the bar into a heat-set insert. |
| bar_6 | M4x10 csk | S17_V44_AL_flat_bar_front_1x0.25x12in -> S01_V44_PRINT_bottom_plate_left -> S01_V44_PRINT_bottom_plate_right | Flat bar to the printed bottom plate: M4 countersunk up through the bar into a heat-set insert. |
| bar_7 | M4x10 csk | S17_V44_AL_flat_bar_rear_1x0.25x12in -> S01_V44_PRINT_bottom_plate_left -> S01_V44_PRINT_bottom_plate_right | Flat bar to the printed bottom plate: M4 countersunk up through the bar into a heat-set insert. |
| bar_8 | M4x10 csk | S17_V44_AL_flat_bar_front_1x0.25x12in -> S01_V44_PRINT_bottom_plate_left -> S01_V44_PRINT_bottom_plate_right | Flat bar to the printed bottom plate: M4 countersunk up through the bar into a heat-set insert. |
| bar_9 | M4x10 csk | S17_V44_AL_flat_bar_rear_1x0.25x12in -> S01_V44_PRINT_bottom_plate_left -> S01_V44_PRINT_bottom_plate_right | Flat bar to the printed bottom plate: M4 countersunk up through the bar into a heat-set insert. |
| bar_10 | M4x10 csk | S17_V44_AL_flat_bar_front_1x0.25x12in -> S01_V44_PRINT_bottom_plate_right | Flat bar to the printed bottom plate: M4 countersunk up through the bar into a heat-set insert. |
| bar_11 | M4x10 csk | S17_V44_AL_flat_bar_rear_1x0.25x12in -> S01_V44_PRINT_bottom_plate_right | Flat bar to the printed bottom plate: M4 countersunk up through the bar into a heat-set insert. |
| bar_12 | M4x10 csk | S17_V44_AL_flat_bar_front_1x0.25x12in -> S01_V44_PRINT_bottom_plate_right | Flat bar to the printed bottom plate: M4 countersunk up through the bar into a heat-set insert. |
| bar_13 | M4x10 csk | S17_V44_AL_flat_bar_rear_1x0.25x12in -> S01_V44_PRINT_bottom_plate_right | Flat bar to the printed bottom plate: M4 countersunk up through the bar into a heat-set insert. |
| odrive_foot_0 | M4x16 csk | S17_V44_AL_flat_bar_front_1x0.25x12in -> S01_V44_PRINT_bottom_plate_right -> MOUNT_ODrive_Pro_bracket_printed_PA-CF_base-mounted | ODrive bracket foot: M4 up through bar and plate slot into its insert. |
| odrive_foot_1 | M4x16 csk | S17_V44_AL_flat_bar_rear_1x0.25x12in -> S01_V44_PRINT_bottom_plate_right -> MOUNT_ODrive_Pro_bracket_printed_PA-CF_base-mounted | ODrive bracket foot: M4 up through bar and plate slot into its insert. |
| exit_plate_0 | M4x10 csk | S01_V44_PRINT_bottom_plate_right -> FM10_Square_back_plate_4-screw_enclosure_mount | Square back plate (fairlead) to the bottom plate: M4 up into its insert. |
| exit_plate_1 | M4x10 csk | S01_V44_PRINT_bottom_plate_right -> FM10_Square_back_plate_4-screw_enclosure_mount | Square back plate (fairlead) to the bottom plate: M4 up into its insert. |
| board_plate_0 | M3x6 socket | S01_V44_PRINT_bottom_plate_left -> MOUNT_front_board_plate_printed | Front board plate foot: M3 up through the plate (head in a counterbore) into its insert. |
| board_plate_1 | M3x6 socket | S01_V44_PRINT_bottom_plate_left -> MOUNT_front_board_plate_printed | Front board plate foot: M3 up through the plate (head in a counterbore) into its insert. |
| cover_back_0 | M3x10 csk | S01_V44_PRINT_bottom_plate_left -> V44_PRINT_cover_left_screen | Cover to the rear plate: M3 countersunk from the back (flush, D6) into the cover boss insert. |
| cover_back_1 | M3x10 csk | S01_V44_PRINT_bottom_plate_left -> V44_PRINT_cover_left_screen | Cover to the rear plate: M3 countersunk from the back (flush, D6) into the cover boss insert. |
| cover_back_2 | M3x10 csk | S01_V44_PRINT_bottom_plate_left -> S01_V44_PRINT_bottom_plate_right -> V44_PRINT_cover_left_screen | Cover to the rear plate: M3 countersunk from the back (flush, D6) into the cover boss insert. |
| cover_back_3 | M3x10 csk | S01_V44_PRINT_bottom_plate_right -> V44_PRINT_cover_right_grille | Cover to the rear plate: M3 countersunk from the back (flush, D6) into the cover boss insert. |
| cover_back_4 | M3x10 csk | S01_V44_PRINT_bottom_plate_right -> V44_PRINT_cover_right_grille | Cover to the rear plate: M3 countersunk from the back (flush, D6) into the cover boss insert. |
| cover_foot_0 | M3x8 csk | S01_V44_PRINT_bottom_plate_left -> V44_PRINT_cover_left_screen | Cover / cap foot boss: M3 up through the plate into its insert. |
| cover_foot_1 | M3x8 csk | S01_V44_PRINT_bottom_plate_left -> S01_V44_PRINT_bottom_plate_right -> V44_PRINT_cover_left_screen | Cover / cap foot boss: M3 up through the plate into its insert. |
| cover_foot_2 | M3x8 csk | S01_V44_PRINT_bottom_plate_right -> V44_PRINT_cover_right_grille | Cover / cap foot boss: M3 up through the plate into its insert. |
| cover_foot_3 | M3x8 csk | S01_V44_PRINT_bottom_plate_right -> V44_PRINT_cover_right_grille | Cover / cap foot boss: M3 up through the plate into its insert. |
| cover_foot_4 | M3x8 csk | S01_V44_PRINT_bottom_plate_right -> V44_PRINT_cover_right_grille | Cover / cap foot boss: M3 up through the plate into its insert. |
| cover_foot_5 | M3x8 csk | S01_V44_PRINT_bottom_plate_right -> V44_PRINT_cover_right_grille | Cover / cap foot boss: M3 up through the plate into its insert. |
| cover_foot_6 | M3x8 csk | S01_V44_PRINT_bottom_plate_right -> V44_PRINT_cover_right_grille | Cover / cap foot boss: M3 up through the plate into its insert. |
| cover_foot_7 | M3x8 csk | S01_V44_PRINT_bottom_plate_right -> V44_PRINT_cover_right_grille -> V44_PRINT_end_cap_battery | Cover / cap foot boss: M3 up through the plate into its insert. |
| cover_foot_8 | M3x8 csk | S01_V44_PRINT_bottom_plate_left -> V44_PRINT_end_cap_motor | Cover / cap foot boss: M3 up through the plate into its insert. |
| cover_foot_9 | M3x16 csk | S17_V44_AL_flat_bar_rear_1x0.25x12in -> S01_V44_PRINT_bottom_plate_left -> V44_PRINT_end_cap_motor | Cover / cap foot boss: M3 up through the bar and plate into its insert. |
| cover_foot_10 | M3x8 csk | S01_V44_PRINT_bottom_plate_right -> V44_PRINT_end_cap_battery | Cover / cap foot boss: M3 up through the plate into its insert. |
| fan_0 | M3x25 csk | S01_V44_PRINT_bottom_plate_right -> MOUNT_fan_duct_mount_frame_printed -> TRIAL_driver_fan | ODrive fan: M3 countersunk from the back (flush, D6) through the rear plate and duct, self-tapping into the fan corner holes. |
| fan_1 | M3x25 csk | S01_V44_PRINT_bottom_plate_right -> MOUNT_fan_duct_mount_frame_printed -> TRIAL_driver_fan | ODrive fan: M3 countersunk from the back (flush, D6) through the rear plate and duct, self-tapping into the fan corner holes. |
| fan_2 | M3x25 csk | S01_V44_PRINT_bottom_plate_right -> MOUNT_fan_duct_mount_frame_printed -> TRIAL_driver_fan | ODrive fan: M3 countersunk from the back (flush, D6) through the rear plate and duct, self-tapping into the fan corner holes. |
| fan_3 | M3x25 csk | S01_V44_PRINT_bottom_plate_right -> MOUNT_fan_duct_mount_frame_printed -> TRIAL_driver_fan | ODrive fan: M3 countersunk from the back (flush, D6) through the rear plate and duct, self-tapping into the fan corner holes. |
| wago_bracket_0 | M3x8 socket | MOUNT_power_junction_bracket_printed -> S01_V44_PRINT_bottom_plate_right | WAGO bracket: M3 into a rear-plate insert. |
| wago_bracket_1 | M3x8 socket | MOUNT_power_junction_bracket_printed -> S01_V44_PRINT_bottom_plate_right | WAGO bracket: M3 into a rear-plate insert. |
| screen_leg_0 | M3x8 csk | V44_PRINT_cover_left_screen -> MOUNT_screen_rear_retaining_frame_printed | Screen frame leg: M3 countersunk from the front (flush under the bezel edge) into the leg insert. |
| screen_leg_1 | M3x8 csk | V44_PRINT_cover_left_screen -> MOUNT_screen_rear_retaining_frame_printed | Screen frame leg: M3 countersunk from the front (flush under the bezel edge) into the leg insert. |
| pi_top_0 | M2.5x5 csk | V44_PRINT_cover_left_screen -> MOUNT_Pi_ceiling_standoffs_M2.5 | Pi standoff to the cover top: M2.5 countersunk from above. |
| pi_board_0 | M2.5x6 socket | TRIAL_Pi4_upright -> MOUNT_Pi_ceiling_standoffs_M2.5 | Pi to its standoff: M2.5 from below through the board. |
| pi_top_1 | M2.5x5 csk | V44_PRINT_cover_left_screen -> MOUNT_Pi_ceiling_standoffs_M2.5 | Pi standoff to the cover top: M2.5 countersunk from above. |
| pi_board_1 | M2.5x4 socket | TRIAL_Pi4_upright -> MOUNT_Pi_ceiling_standoffs_M2.5 | Pi to its standoff: M2.5 from below through the board. |
| pi_top_2 | M2.5x5 csk | V44_PRINT_cover_left_screen -> MOUNT_Pi_ceiling_standoffs_M2.5 | Pi standoff to the cover top: M2.5 countersunk from above. |
| pi_board_2 | M2.5x4 socket | TRIAL_Pi4_upright -> MOUNT_Pi_ceiling_standoffs_M2.5 | Pi to its standoff: M2.5 from below through the board. |
| pi_top_3 | M2.5x5 csk | V44_PRINT_cover_left_screen -> MOUNT_Pi_ceiling_standoffs_M2.5 | Pi standoff to the cover top: M2.5 countersunk from above. |
| pi_board_3 | M2.5x4 socket | TRIAL_Pi4_upright -> MOUNT_Pi_ceiling_standoffs_M2.5 | Pi to its standoff: M2.5 from below through the board. |
| bms_4 | M3x12 csk | V44_PRINT_cover_right_grille -> MOUNT_BMS_ceiling_standoffs_M3 -> JBD_SP17S005_BMS_mock_from_spec | BMS to the cover top: M3 countersunk from above through the spacer and board, nut under the board. |
| bms_5 | M3x12 csk | V44_PRINT_cover_right_grille -> MOUNT_BMS_ceiling_standoffs_M3 -> JBD_SP17S005_BMS_mock_from_spec | BMS to the cover top: M3 countersunk from above through the spacer and board, nut under the board. |
| bms_6 | M3x12 csk | V44_PRINT_cover_right_grille -> MOUNT_BMS_ceiling_standoffs_M3 -> JBD_SP17S005_BMS_mock_from_spec | BMS to the cover top: M3 countersunk from above through the spacer and board, nut under the board. |
| bms_7 | M3x12 csk | V44_PRINT_cover_right_grille -> MOUNT_BMS_ceiling_standoffs_M3 -> JBD_SP17S005_BMS_mock_from_spec | BMS to the cover top: M3 countersunk from above through the spacer and board, nut under the board. |
| xt60_0 | M2.5x5 csk | AMASS_XT60E-F_charge_port -> V44_PRINT_rear_IO_panel_flush | XT60E-F flange: M2.5 countersunk (countersink the flange holes) self-tapping into the backing frame. |
| xt60_1 | M2.5x5 csk | AMASS_XT60E-F_charge_port -> V44_PRINT_rear_IO_panel_flush | XT60E-F flange: M2.5 countersunk (countersink the flange holes) self-tapping into the backing frame. |
| io_tab_0 | M2.5x5 socket | V44_PRINT_rear_IO_panel_flush -> V44_PRINT_cover_right_grille | Rear I/O panel tab: M2.5 self-tapping into the step wall. |
| io_tab_1 | M2.5x5 socket | V44_PRINT_rear_IO_panel_flush -> V44_PRINT_cover_right_grille | Rear I/O panel tab: M2.5 self-tapping into the step wall. |
| odrive_spreader_0 | M4x12 socket | V3_ODrive_heat_spreader_SUPPLIER_CAD -> MOUNT_ODrive_Pro_bracket_printed_PA-CF_base-mounted | ODrive heat spreader to the bracket post: M4 from the board side, nut in the hex pocket on the far face. |
| odrive_spreader_1 | M4x12 socket | V3_ODrive_heat_spreader_SUPPLIER_CAD -> MOUNT_ODrive_Pro_bracket_printed_PA-CF_base-mounted | ODrive heat spreader to the bracket post: M4 from the board side, nut in the hex pocket on the far face. |
| odrive_spreader_2 | M4x12 socket | V3_ODrive_heat_spreader_SUPPLIER_CAD -> MOUNT_ODrive_Pro_bracket_printed_PA-CF_base-mounted | ODrive heat spreader to the bracket post: M4 from the board side, nut in the hex pocket on the far face. |
| odrive_spreader_3 | M4x12 socket | V3_ODrive_heat_spreader_SUPPLIER_CAD -> MOUNT_ODrive_Pro_bracket_printed_PA-CF_base-mounted | ODrive heat spreader to the bracket post: M4 from the board side, nut in the hex pocket on the far face. |
| standoff_Teensy_0 | M2.5x12 socket | TRIAL_Teensy -> MOUNT_Teensy_perfboard_standoffs -> MOUNT_front_board_plate_printed | Board standoff: M2.5 through the board and the standoff into a front-plate insert. |
| standoff_Teensy_1 | M2.5x12 socket | TRIAL_Teensy -> MOUNT_Teensy_perfboard_standoffs -> MOUNT_front_board_plate_printed | Board standoff: M2.5 through the board and the standoff into a front-plate insert. |
| standoff_CAN_0 | M2.5x10 socket | TRIAL_CAN_headers -> MOUNT_CAN_board_perfboard_standoffs -> MOUNT_front_board_plate_printed | Board standoff: M2.5 through the board and the standoff into a front-plate insert. |
| standoff_CAN_1 | M2.5x10 socket | TRIAL_CAN_headers -> MOUNT_CAN_board_perfboard_standoffs -> MOUNT_front_board_plate_printed | Board standoff: M2.5 through the board and the standoff into a front-plate insert. |
| standoff_CAN_2 | M2.5x10 socket | TRIAL_CAN_headers -> MOUNT_CAN_board_perfboard_standoffs -> MOUNT_front_board_plate_printed | Board standoff: M2.5 through the board and the standoff into a front-plate insert. |
| standoff_CAN_3 | M2.5x10 socket | TRIAL_CAN_headers -> MOUNT_CAN_board_perfboard_standoffs -> MOUNT_front_board_plate_printed | Board standoff: M2.5 through the board and the standoff into a front-plate insert. |
| standoff_regulator_0 | M2.5x12 socket | TRIAL_Pololu5571 -> MOUNT_regulator_perfboard_standoffs -> MOUNT_front_board_plate_printed | Board standoff: M2.5 through the board and the standoff into a front-plate insert. |
| standoff_regulator_1 | M2.5x12 socket | TRIAL_Pololu5571 -> MOUNT_regulator_perfboard_standoffs -> MOUNT_front_board_plate_printed | Board standoff: M2.5 through the board and the standoff into a front-plate insert. |
| standoff_regulator_2 | M2.5x12 socket | TRIAL_Pololu5571 -> MOUNT_regulator_perfboard_standoffs -> MOUNT_front_board_plate_printed | Board standoff: M2.5 through the board and the standoff into a front-plate insert. |
| standoff_regulator_3 | M2.5x12 socket | TRIAL_Pololu5571 -> MOUNT_regulator_perfboard_standoffs -> MOUNT_front_board_plate_printed | Board standoff: M2.5 through the board and the standoff into a front-plate insert. |

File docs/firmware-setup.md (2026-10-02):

# Electronics and firmware setup

The control app (Raspberry Pi touch screen + Teensy 4.0 over CAN to the ODrive) is not part of this release yet.
This page covers what must be configured before the motor is ever powered with the rope attached.

## Power path

- Pack: 2 x Thunder Power TP2700-5SR70 (5S) in series = 10S, 30-42 V, through a JBD SP17S005 10S BMS.
- The power button on the rear I/O panel switches the BMS (signal only). The EC5 plugs on the packs are the service
  disconnect: plug them in with the BMS switched off.
- Charging: XT60E-F port on the rear panel -> 7.5 A 58 V fuse -> BMS. Charge to about 80 % for training (room for braking energy).
- See `wiring.md` for every wire.

## ODrive Pro

Check the property names against the documentation for your firmware version.

| Setting | Value | Why |
|---|---|---|
| DC bus over-voltage trip | about 45 V | under the ODrive (58 V) and regulator (60 V) limits; braking energy charges the pack |
| Max regen (negative DC) current | 28 A | what the BMS and wiring are sized for |
| Motor | your motor's pole pairs, Kv, current limit | the reference motor is about 50 Kv, 13 N·m peak, 1.25 kg |
| Encoder | the ODrive Pro's on-board MA702 with the diametric magnet on the drum-shaft end | absolute within one turn only |

## Payout window (must be set)

The drum is direct-drive (one motor turn = one drum turn, 157.6 mm of rope per turn at the rope centre).

1. **Home** at power-up: wind the rope fully in until the handle stops at the exit (low torque, current-limited); that is
   position 0 (the fairlead carrier is then at +45.4 deg).
2. **Payout limit:** 13.26 turns from home (full payout is 13.36 turns, where the rope reaches the 3 hand-wound dead wraps;
   the limit keeps 16 mm in hand).
3. Enforce the window in the controlling firmware (Teensy) and, where your ODrive firmware supports position limits, in the
   ODrive as well.

The two hard stops on the fairlead carrier engage 0.45 turn past full payout (+-48.4 deg). They are an assembly / hand-turning
backstop only: the worm cannot be back-driven, so hitting a stop under power locks the drum through the gear train.

| Check | Value |
|---|---|
| Tracked rope (full wind to full payout) | 2.11 m, 13.36 drum turns |
| Carrier swing over that range | +45.4 deg (full wind) to -45.4 deg (full payout), 1/53 of a turn per drum turn |
| Hard stops | +-48.4 deg (clear at 48.4, blocked by 48.8 in CAD) |
| Rope lay pitch on the drum | 3.3-5.8 mm per turn (rope 3.175 mm), never overlapping |

## First power-up checklist

1. Rope off the drum or unloaded. Power on; if the BMS trips on the ODrive's capacitor inrush, lengthen the BMS short-circuit
   delay in the BMS app.
2. Calibrate the motor and encoder (ODrive procedure).
3. Turn the drum slowly by command: confirm the direction that winds the rope in, and that the fairlead carrier moves toward
   +45 deg while winding.
4. Set and test the payout window with the rope attached and no load.
5. Static load test in steps (see `SAFETY.md`).

## Teensy 4.0

- Power: 5 V from the regulator to VIN; **cut the VIN-VUSB pad** (it is also connected to the Pi by USB).
- CAN: Teensy CAN TX/RX to the SN65HVD230 board, CAN H / L / GND to the ODrive CAN header (twisted pair).

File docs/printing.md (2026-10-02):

# Printing

All printed parts are in `print/` (STL, in the assembly frame: orient them in the slicer, see the "face down" column in
`print/README.md`). Every hole is already at its final size for the inserts and screws.

## Materials

- **Structural** (bottom plates, fairlead carrier and back plate, ODrive bracket, bearing cartridges, gussets): PA-CF
  (PAHT-CF), dried before printing.
- **Covers and end caps:** PETG-CF or PA-CF.
- **Light brackets** (screen frame, board plate, WAGO bracket, fan duct): PETG is fine.

Suggested settings for the structural parts (not yet validated by a load test): 0.2 mm layers, 5-6 walls, 6 top/bottom layers,
40-50 % gyroid infill, print the bottom plates flat on their underside. All parts fit a 256 mm bed (Bambu P2S class).

## Fit coupons first

`print/fit-coupons/` tests the tolerances in your material before the big prints:

1. Insert pockets M2.5 / M3 / M4 at -0.15 / nominal / +0.15 mm (Ruthex RX, pockets 3.6 / 4.0 / 5.6 mm).
2. Clearance holes M2.5 / M3 / M4 and the 5.2 mm pulley axle at -0.2 / nominal / +0.2 mm.
3. A 10 mm slice of the battery saddle (40.0 mm inside): slide a pack through it.
4. The exit pulley axles, 21.13 mm apart, with the carrier walls.
5. The 6809 bearing seat (58 mm): the bearing should press in by hand.

If your printer needs different sizes, adjust the holes in the FreeCAD parts (or the `source/` scripts) and re-export.

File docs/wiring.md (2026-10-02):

# Wiring

Every wire below is modelled in the CAD (`WIRE_*` parts, routed through the enclosure with their real insulation diameter),
so the lengths are the routed lengths; add 10-15 % for the terminations. Gauges are the minimum.

## Power path

```mermaid
flowchart LR
  A["Pack A 5S"] -- "series link (EC5)" --> B["Pack B 5S"]
  B -- "B+ 10 AWG" --> FL["Main fuse 40 A 58 V<br/>line stud"]
  FL --> FLD["load stud"]
  FLD -- "10 AWG" --> OD["ODrive Pro DC+"]
  FLD -- "18 AWG" --> F3["3 A 58 V fuse"] --> REG["5 V regulator<br/>Pololu D42V55F5"]
  CH["XT60E-F charge port"] -- "16 AWG" --> F7["7.5 A 58 V fuse"] --> FL
  A -- "A- 10 AWG" --> BMS["BMS B-<br/>JBD SP17S005"]
  BMS -- "P- 10 AWG" --> W["WAGO 221-615<br/>P- junction"]
  W -- "10 AWG" --> ODM["ODrive Pro DC-"]
  W -- "16 AWG" --> CH
  W -- "18 AWG" --> REG
  SW["Power button"] -- "signal pair" --> BMS
  REG -- "5 V" --> PI["Raspberry Pi 4"]
  REG -- "5 V" --> T["Teensy 4.0"]
  REG -- "5 V" --> FAN["ODrive fan"]
  T -- "CAN" --> CANB["SN65HVD230"] -- "CAN H/L" --> OD
  T -- "USB" --> PI
```

Every return goes through the BMS P- (the WAGO), so the BMS can switch everything off. Charging enters at the main fuse's
line stud through its own 7.5 A fuse (it bypasses the 40 A fuse; the BMS still controls it).

## Wire list

| Wire | Gauge | Route / ends | Length |
|---|---|---|---|
| DSI ribbon 15way FFC | FFC | Display ribbon: 15-way 1 mm FFC from the screen connector, behind the screen stand, up the back of the screen to the Pi DSI port. | - |
| pack plus B+ to fuse line 10AWG | 10AWG | Pack B+ (EC5 on the pack lead) to the main fuse line stud (ring terminal inside the holder). | 172 mm |
| series link A+ to B- 10AWG | 10AWG | Series link between the two 5S packs (EC5 pair), in the back step. | 53 mm |
| pack minus A- to BMS B- 10AWG | 10AWG | Pack A- (EC5) to the BMS B- pad (soldered; pad position is the mock's). | 124 mm |
| ODrive DC+ from fuse load 10AWG | 10AWG | Main fuse load stud to ODrive DC+ (TB005 pole 1; ferrule). | 30 mm |
| ODrive DC- from WAGO 10AWG | 10AWG | WAGO port 1 to ODrive DC- (TB005 pole 2; ferrule). | 42 mm |
| BMS P- to WAGO 10AWG | 10AWG | BMS P- pad to the WAGO (port 2). | 164 mm |
| motor phase C 12AWG | 12AWG | Motor phase C: out of the lead-exit endcap, through the 12 mm grommet in the face plate, to TB005 pole 5 (ferrule). Gauge and exit point to confirm on the motor. | 304 mm |
| motor phase B 12AWG | 12AWG | Motor phase B: out of the lead-exit endcap, through the 12 mm grommet in the face plate, to TB005 pole 4 (ferrule). Gauge and exit point to confirm on the motor. | 315 mm |
| motor phase A 12AWG | 12AWG | Motor phase A: out of the lead-exit endcap, through the 12 mm grommet in the face plate, to TB005 pole 3 (ferrule). Gauge and exit point to confirm on the motor. | 280 mm |
| charge plus XT60 to inline fuse 16AWG | 16AWG | Charge port + (upper cup, per the panel marking) to the 7.5 A inline fuse. | 40 mm |
| charge plus inline fuse to line 16AWG | 16AWG | 7.5 A inline fuse to the main fuse line stud (charging bypasses the 40 A fuse, the BMS still switches it). | 79 mm |
| charge minus XT60 to WAGO 16AWG | 16AWG | Charge port - (lower cup) to the WAGO (port 3). | 126 mm |
| regulator feed fuse load to inline fuse 18AWG | 18AWG | Main fuse load stud to the 3 A inline fuse. | 147 mm |
| regulator VIN+ from inline fuse 18AWG | 18AWG | 3 A inline fuse to the regulator VIN (screw terminal on its perfboard). | 338 mm |
| regulator VIN- to WAGO 18AWG | 18AWG | WAGO port 4 to the regulator GND in. | 412 mm |
| 5V Pi plus 20AWG | 20AWG | Regulator 5 V out to Pi GPIO pin 2. | 131 mm |
| 5V Pi minus 20AWG | 20AWG | Regulator GND to Pi GPIO pin 6. | 131 mm |
| 5V fan plus 24AWG | 24AWG | Regulator 5 V out to the ODrive fan (fan lead extended). | 411 mm |
| 5V fan minus 24AWG | 24AWG | Regulator GND to the ODrive fan. | 413 mm |
| 5V Teensy VIN 22AWG | 22AWG | Regulator 5 V out to Teensy VIN (cut the VIN-VUSB pad). | 77 mm |
| 5V Teensy GND 22AWG | 22AWG | Regulator GND to Teensy GND. | 91 mm |
| Teensy to CAN board 4x26AWG | 4x26AWG | Teensy CAN TX/RX, 3.3 V and GND to the CAN transceiver board (short bundle on the front plate). | 26 mm |
| CAN bus to ODrive twisted pair | twisted_pair | CAN H / CAN L / GND (twisted pair + drain) from the CAN board terminal to the ODrive CAN header, in front of the BMS. | 350 mm |
| USB Teensy to Pi | - | USB cable, Teensy (micro-USB, right angle) to the Pi upper USB-A port (right angle). | 177 mm |
| balance lead pack A | - | Pack A balance lead (cells 1-5) to the BMS balance header. | 177 mm |
| balance lead pack B | - | Pack B balance lead (cells 6-10) to the BMS balance header. | 128 mm |
| BMS NTC lead | - | BMS NTC lead to the probe on pack B. | 108 mm |
| power switch to BMS pair | - | Power switch to the BMS soft-switch input (twisted pair). | 128 mm |

## Notes

- **Fuses must be rated 58 V** (Littelfuse BF1 MIDI 40 A, Littelfuse 997 MINI 3 A and 7.5 A). Common 32 V automotive fuses are not.
- EC5 plugs on the pack leads are the service disconnect: plug in with the BMS switched off.
- WAGO 221-615 is rated about 30 A (UL); the peak pull is about 28 A for short reps.
- Teensy: cut the VIN-VUSB pad (powered by the regulator and connected to the Pi by USB).
- Motor phase leads: gauge and exit point depend on your motor; the model assumes 12 AWG through a 12 mm grommet.
- Crimp ferrules on every wire into the ODrive terminal block; ring terminals on the fuse-holder studs.

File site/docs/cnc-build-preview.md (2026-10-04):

# CNC build: illustrated preview

**Build instructions and updated CAD are upcoming.** These stills are taken from the CNC assembly segment of the KINETIQ Blender animation. They explain the proposed layout; they are not a confirmed fabrication or assembly procedure. The earlier prototype files in the repository and this film may show different revisions.

## 1. Aluminum structure and welded joints

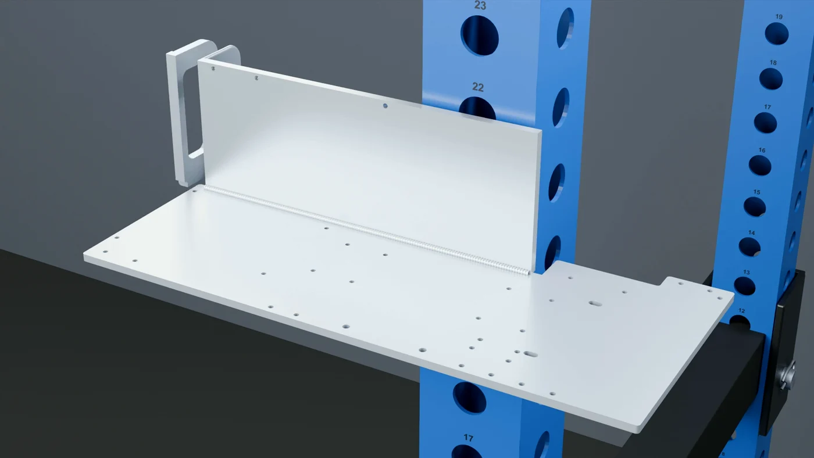
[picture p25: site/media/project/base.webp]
Flat CNC base, rear plate and rack mount from the assembly animation


The bottom and rear plates are aluminum. Separate plate connections and the rack-mount cheeks are shown as weld steps. The mount is attached before the hitch pin enters the rack. Final drawings, weld specifications and inspection details are pending.

## 2. Drum, bearings and fairlead

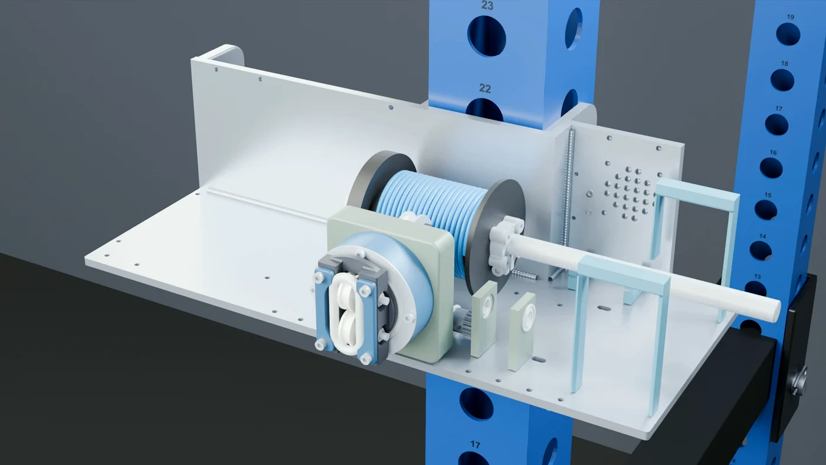
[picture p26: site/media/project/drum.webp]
Drum, rope and fairlead assembled in their installed locations


The drum and fairlead assemble at their installed positions. The illustration shows the shaft, bearing supports, transmission and wound rope together. Updated drum dimensions and fairlead geometry will be documented with the coordinated CAD release.

## 3. Motor, electronics and power

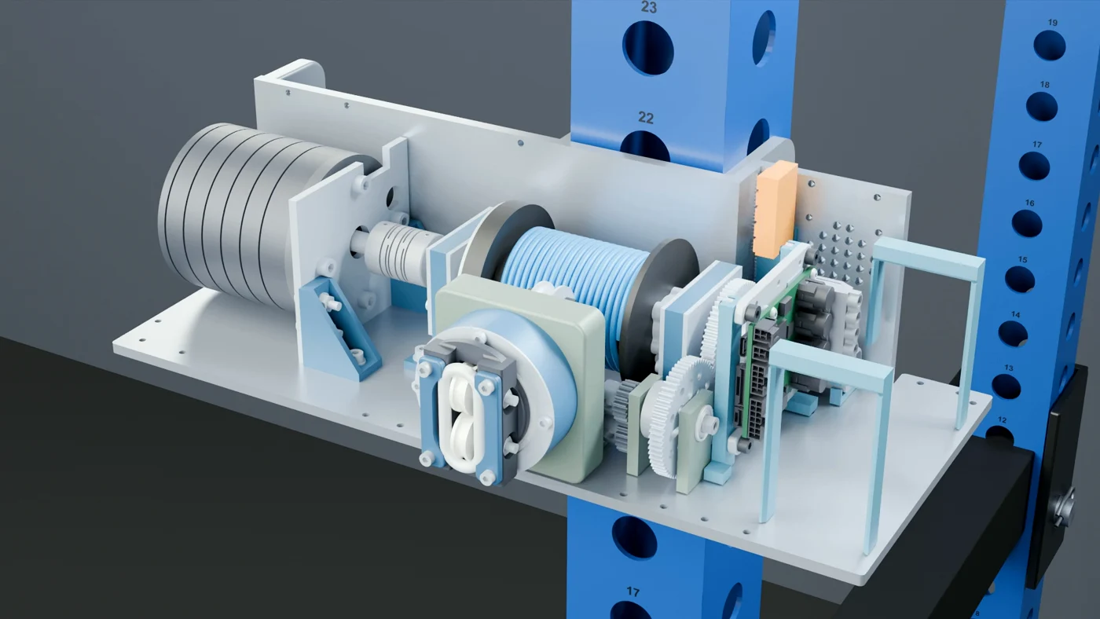
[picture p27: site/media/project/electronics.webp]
Motor, controller and electronics on the CNC base


The drive and electronics surround the rope mechanism. The proposed battery removal path slides the packs into their saddles. Final wiring, fastener details, control firmware and validation procedures are still being developed. See the [draft wiring reference](wiring.md) for the earlier prototype.

## 4. Printed enclosure and touchscreen

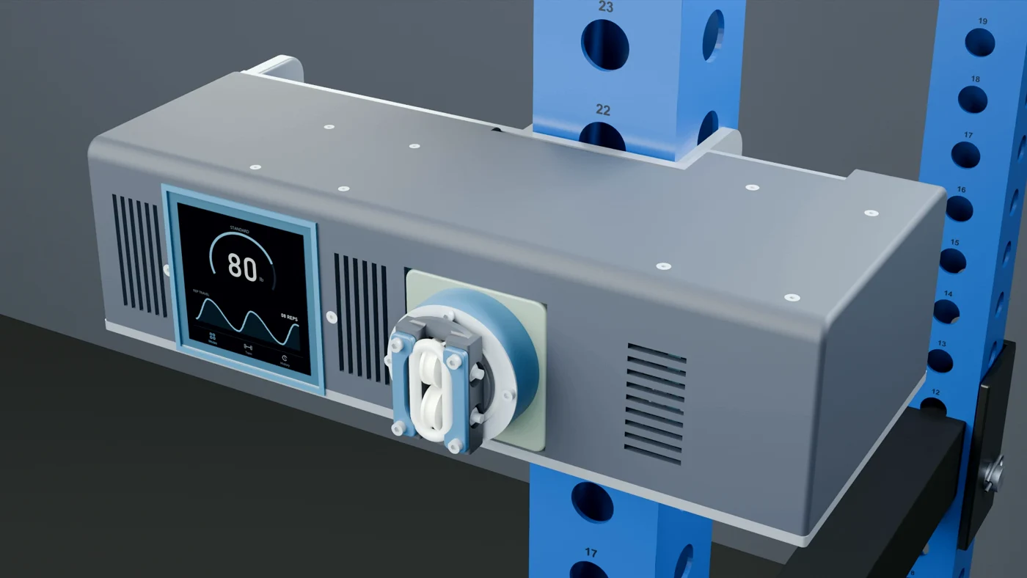
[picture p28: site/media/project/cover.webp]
Assembled CNC trainer with a light gray printed cover


The printed cover and carry handle complete the aluminum build. The touchscreen in the animation is an interface concept. Fit, clearances and installation details remain part of prototype development.

## Follow the next release

View the [public repository](https://github.com/TrentIndeed/kinetiqgym), [contribution guide](CONTRIBUTING.md) and [project roadmap](roadmap.md). The confirmed parts list, build instructions, updated models, Pi app and Teensy programs will be published as they become ready.

Animation imagery © KINETIQ project, shared with the project documentation under CC BY-SA 4.0. Depictions of third-party components identify their role in the concept; they do not imply endorsement.

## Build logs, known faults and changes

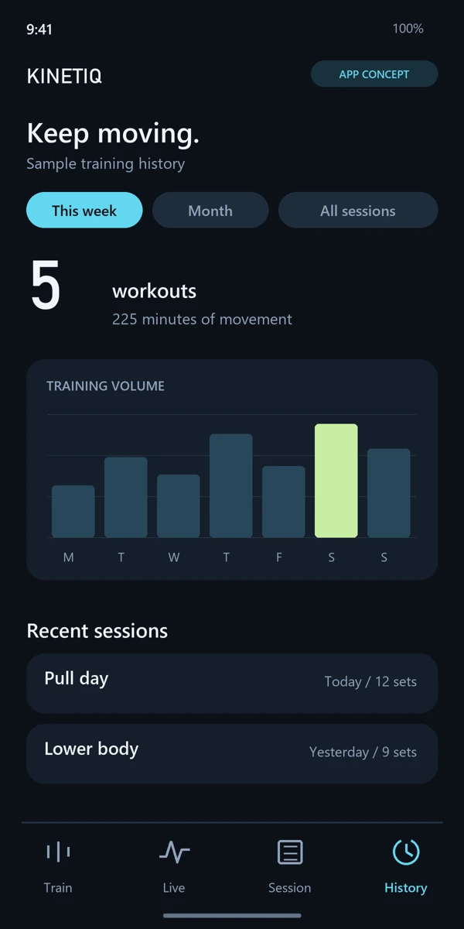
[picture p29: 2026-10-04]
site/media/project/app-history.webp

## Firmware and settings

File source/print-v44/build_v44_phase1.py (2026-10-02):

"""V44 phase 1: every current live-demo part as real CAD in the workbench source format (like print-v42).

world solid = M (S(source) - c): M and c from the page (demo-placements-rev12.json, design layout rev 12), S from register_sources.py.
Parts without a CAD source (battery, BMS, allowances, perfboard footprints) are rebuilt as solids from the demo
mesh (boxes, or sewn triangles). Stale sources (motor face plate, anchor rope) are trimmed to the demo's bounds.
Changes against the demo, per the V44 decisions: the rigid Ruland envelope is replaced by the user's flexible
coupler from V42, and the base placeholder is left out (a new chassis replaces it in phase 3).
Writes {cnc,printed}/revision.json + <name>.step/.brep + hardware.csv. Engineering preview: no release checks yet.
"""
from pathlib import Path
import json, sys, gzip, re, csv, shutil
import numpy as np
import cadquery as cq
from OCP.BRepBuilderAPI import BRepBuilderAPI_Sewing, BRepBuilderAPI_MakePolygon, BRepBuilderAPI_MakeFace, BRepBuilderAPI_MakeSolid
from OCP.gp import gp_Pnt
from OCP.TopoDS import TopoDS
from OCP.TopAbs import TopAbs_SHELL
from OCP.TopExp import TopExp_Explorer

HERE = Path(__file__).resolve().parent; R = HERE.parent
PL = json.loads((HERE / 'demo-placements-rev12.json').read_text(encoding='utf-8-sig'))['rows']
SRC = json.loads((HERE / 'sources.json').read_text())['sources']
MODEL = {p['name']: p for p in json.loads(gzip.decompress((R / 'workbench/public/stock-battery-fit/editor-model-tp2700.json.gz').read_bytes()))['parts']}
EXCLUDE = {'TRIAL_base_placeholder': 'replaced by the new V44 chassis (phase 3)',
           'V43_REF_Ruland_MCLX_12_10_F_ENVELOPE': 'replaced by the user-confirmed flexible coupler (V42)'}
TRIM = ('V43_METAL_motor_face_4mm', 'V27_REF_anchor_cable')      # source older than the demo: trim to the demo bounds
TRIM_SRC = {n: R / 'prototype-v43' / (n + '.brep') for n in TRIM}

def safe(n):
    s = re.sub(r'[^A-Za-z0-9_.-]+', '_', n.replace('×', 'x').replace('—', '-')).strip('_.')
    return re.sub(r'_+', '_', s)[:96]

def world_matrix(row):
    el = row['m']; A = np.array([[el[j * 4 + i] for j in range(4)] for i in range(4)])     # three.js column-major
    T = np.eye(4); T[:3, 3] = -np.array(row['c'])
    return A @ T

def apply(shape, A):
    """Rigid transform. The page's matrices are rounded to 6 decimals: re-orthogonalise the rotation (SVD) first."""
    from OCP.gp import gp_Trsf
    from OCP.BRepBuilderAPI import BRepBuilderAPI_Transform
    U, _, Vt = np.linalg.svd(A[:3, :3]); Rm = U @ Vt
    if np.linalg.det(Rm) < 0: raise ValueError('mirror transform')
    t = A[:3, 3]; tr = gp_Trsf()
    tr.SetValues(*[float(x) for x in (Rm[0, 0], Rm[0, 1], Rm[0, 2], t[0], Rm[1, 0], Rm[1, 1], Rm[1, 2], t[1], Rm[2, 0], Rm[2, 1], Rm[2, 2], t[2])])
    out = cq.Shape.cast(BRepBuilderAPI_Transform(shape.wrapped, tr, True).Shape())
    fch = sys.modules.get('fchist_rec')                                # FreeCAD history (FCHIST=1): record the move
    if fch: fch.tag_xform(out, shape, [[Rm[i, 0], Rm[i, 1], Rm[i, 2], t[i]] for i in range(3)])
    return out

def box_from(b):
    return cq.Solid.makeBox(b[3] - b[0], b[4] - b[1], b[5] - b[2], cq.Vector(b[0], b[1], b[2]))

def sew(vis):
    v = np.array(vis['vertices'], float).reshape(-1, 3); t = np.array(vis['triangles']).reshape(-1, 3)
    if len(t) == 12: return box_from([*v.min(0), *v.max(0)])
    sw = BRepBuilderAPI_Sewing(1e-3)
    for a, b, c in t:
        pa, pb, pc = (gp_Pnt(*map(float, v[k])) for k in (a, b, c))
        if pa.Distance(pb) < 1e-6 or pb.Distance(pc) < 1e-6 or pa.Distance(pc) < 1e-6: continue
        poly = BRepBuilderAPI_MakePolygon(pa, pb, pc, True); sw.Add(BRepBuilderAPI_MakeFace(poly.Wire()).Face())
    sw.Perform(); ex = TopExp_Explorer(sw.SewedShape(), TopAbs_SHELL); solids = []
    while ex.More():
        ms = BRepBuilderAPI_MakeSolid(TopoDS.Shell_s(ex.Current()))
        if ms.IsDone():
            s = cq.Solid(ms.Solid())
            if s.isValid() and abs(s.Volume()) > 1e-3: solids.append(s if s.Volume() > 0 else cq.Solid(s.wrapped.Reversed()))
        ex.Next()
    return cq.Compound.makeCompound(solids) if solids else box_from([*v.min(0), *v.max(0)])

VEND = R / 'rectangular-body-study/vendor'
COMPOSITE = {'TRIAL_Pololu5571': VEND / 'pololu.brep', 'TRIAL_CAN_headers': VEND / 'waveshare-can.brep', 'TRIAL_Teensy': VEND / 'teensy40.brep'}   # vendor board + perfboard box

def register_vendor(shape, visuals):
    """Place a vendor-frame solid on the demo's board mesh: best of 24 axis rotations by surface distance."""
    import itertools, trimesh
    vs, ts, k = [], [], 0
    for vis in visuals:
        a = np.array(vis['vertices'], float).reshape(-1, 3); vs.append(a); ts.append(np.array(vis['triangles']).reshape(-1, 3) + k); k += len(a)
    mesh = trimesh.Trimesh(np.vstack(vs), np.vstack(ts), process=False); mlo, mhi = mesh.bounds
    v, _ = shape.tessellate(.2, .3); sp = np.array([q.toTuple() for q in v])
    sp = sp[np.random.default_rng(0).choice(len(sp), min(1500, len(sp)), replace=False)]
    best = None
    for perm in itertools.permutations(range(3)):
        for sg in itertools.product((1, -1), repeat=3):
            Rm = np.zeros((3, 3))
            for i, (j, s) in enumerate(zip(perm, sg)): Rm[i, j] = s
            if np.linalg.det(Rm) < .5: continue
            q = sp @ Rm.T; lo, hi = q.min(0), q.max(0)
            if np.abs((hi - lo) - (mhi - mlo)).max() > 1.5: continue
            t = (mlo + mhi) / 2 - (lo + hi) / 2
            sc = np.percentile(trimesh.proximity.closest_point(mesh, q + t)[1], 95)
            if best is None or sc < best[0]: best = (sc, Rm, t)
    if best is None: raise ValueError('vendor board does not match the demo mesh')
    A = np.eye(4); A[:3, :3] = best[1]; A[:3, 3] = best[2]
    return apply(shape, A), best[0]

def model_shape(n):
    """Shape in the demo's model frame."""
    p = MODEL[n]
    if n in COMPOSITE:
        vis = p.get('visual_parts') or [p]
        boxes = [sew(v) for v in vis if len(v['triangles']) == 36]
        try:
            board, fit = register_vendor(cq.Shape.importBrep(str(COMPOSITE[n])), [v for v in vis if len(v['triangles']) != 36])
        except ValueError:                                           # vendor board does not match the demo's drawing-based mesh
            return cq.Compound.makeCompound([sew(v) for v in vis]), 'rebuilt from the demo mesh (vendor board did not match)'
        return cq.Compound.makeCompound([board, *boxes]), f'CAD: vendor {COMPOSITE[n].name} (fit {fit:.2f} mm) + perfboard footprint rebuilt from the demo'
    if n in SRC and (SRC[n]['status'] == 'exact' or n == 'TRIAL_Pi4_upright'):     # Pi: demo box includes a cooler allowance
        s = SRC[n]; f = R / s['file']
        shp = cq.Shape.importBrep(str(f)) if f.suffix == '.brep' else cq.importers.importStep(str(f)).val()
        Rm = np.array(s['rot']); A = np.eye(4); A[:3, :3] = Rm; A[:3, 3] = s['t']
        return apply(shp, A), 'CAD: ' + s['file']
    if n in TRIM:
        shp = cq.Shape.importBrep(str(TRIM_SRC[n])); return shp.intersect(box_from(p['bounds'])), 'CAD trimmed to the demo edit: ' + str(TRIM_SRC[n].relative_to(R))
    parts = [sew(v) for v in (p.get('visual_parts') or [p])]
    return (parts[0] if len(parts) == 1 else cq.Compound.makeCompound(parts)), 'rebuilt from the demo mesh (no CAD source)'

def group_of(n, row):
    g = row['g']; a = row['asm'] or ''
    if n.startswith('FM10 ') or n.startswith('FM9 Drum') : return 'fairlead' if not n.startswith(('FM9 Drum', 'FM10 Drum')) else 'drivetrain'
    if n.startswith('MOUNT '): return 'mounts'
    if n.startswith('ROUTE ') or g == 'reserve': return 'wiring'
    if a in ('assembly:battery', 'assembly:bms', 'assembly:TRIAL_protection_and_connections') or n == 'RESERVE_battery_connections': return 'power'
    if n == 'V43_PRINT_motor_side_handle': return 'handle'
    if a in ('assembly:drivetrain',): return 'drivetrain'
    return 'electronics'

def kind_of(n, g):
    if g == 'wiring': return 'reference'
    if re.match(r'(FM10 )?(B_|N_|W_|I_|V43_B_|V43_N_|V43_W_|B_V|I_V)', n) or re.search(r'M\d+x\d+|_nut|_washer|Axle_M4', n): return 'fastener'
    if 'spacer' in n.lower(): return 'spacer'
    if re.search(r'6001_2RS|6809|625ZZ|6808|1611|1601', n): return 'bearing_reference'
    if n.startswith(('REF_', 'V3_REF', 'V43_REF', 'CATALOG', 'RESERVE')): return 'reference'
    if 'SUPPLIER' in n or n.startswith(('TRIAL_Pi4', 'TRIAL_driver_fan', 'TRIAL_Waveshare', 'TRIAL_Pololu', 'TRIAL_Teensy', 'TRIAL_CAN')): return 'electronics_reference'
    return 'part'

def manufacture_of(n, row):
    if n.startswith('MOUNT '): return re.search(r'Material: ([^.]+)', MODEL[n].get('description', '')).group(1) if 'Material:' in MODEL[n].get('description', '') else 'PRINT'
    if 'PRINT' in n or 'Printed' in n: return 'PRINT'
    if 'METAL' in n or 'CNC' in n: return 'CNC / cut metal'
    return ''

def main():
    for mode in ('cnc', 'printed'):
        (HERE / mode).mkdir(exist_ok=True)
    names, colors, meta, hardware, report, used = [], {}, {}, [], [], set()
    rows = [r for r in PL if r['n'] not in EXCLUDE]
    coupler = dict(n='REF_coupler_APPROX_10_to_12mm', g='drivetrain', asm='assembly:drivetrain')
    import v44cache as C
    script = C.file_sha(__file__); hits = 0
    def part_key(n, row):
        if n == coupler['n']: return C.sha(script, n, C.file_sha(R / 'print-v42/printed/REF_coupler_APPROX_10_to_12mm.step'))
        files = []
        if n in COMPOSITE: files.append(COMPOSITE[n])
        if n in SRC: files.append(R / SRC[n]['file'])
        if n in TRIM: files.append(TRIM_SRC[n])
        return C.sha(script, n, row['m'], row['c'], row['min'], row['max'], MODEL.get(n), SRC.get(n), [C.file_sha(f) for f in files])
    for row in rows + [coupler]:
        n = row['n']
        v44 = safe(n)
        while v44 in used: v44 += '_x'
        used.add(v44)
        key = part_key(n, row); rec = C.part_get(v44, key)
        if n == coupler['n']:
            p = {'color': [0.72, 0.74, 0.78], 'description': 'USER CONFIRMED flexible aluminium coupling OD25 L30, bores 10/12. Replaces the rigid Ruland envelope of the demo.'}
        else:
            p = MODEL[n]
        if rec:                                                          # unchanged part: reuse the cached solid
            C.part_restore(v44, [HERE / 'cnc', HERE / 'printed']); origin, dev, valid = rec['origin'], rec['dev'], rec['valid']; hits += 1
        else:
            if n == coupler['n']:
                shp = cq.importers.importStep(str(R / 'print-v42/printed/REF_coupler_APPROX_10_to_12mm.step')).val(); origin = 'CAD: print-v42 (user-confirmed flexible coupler OD25 x L30, bores 10/12)'
            else:
                shp, origin = model_shape(n); shp = apply(shp, world_matrix(row))
            if not shp.isValid(): shp = shp.fix()
            bb = shp.BoundingBox(); dev = None
            if n != coupler['n']:
                dev = float(np.abs(np.array([bb.xmin, bb.ymin, bb.zmin, bb.xmax, bb.ymax, bb.zmax]) - np.array(row['min'] + row['max'])).max())
            for mode in ('cnc', 'printed'):
                shp.exportStep(str(HERE / mode / (v44 + '.step'))); shp.exportBrep(str(HERE / mode / (v44 + '.brep')))
            valid = shp.isValid()
            C.part_put(v44, key, HERE / 'printed' / (v44 + '.brep'), HERE / 'printed' / (v44 + '.step'), dict(origin=origin, dev=dev, valid=valid))
        g = group_of(n, row) if n != coupler['n'] else 'drivetrain'; k = kind_of(n, g)
        names.append(v44); colors[v44] = [round(float(c), 3) for c in (p.get('color') or [.7, .7, .7])[:3]]
        meta[v44] = dict(group=g, kind=k, note=(p.get('description') or '')[:400], manufacture=manufacture_of(n, row) if n != coupler['n'] else 'Buy',
                         demo_name=n, source=origin)
        if k in ('fastener', 'spacer', 'bearing_reference'): hardware.append(dict(part=v44, group=g, kind=k, size=n, source='', note=(p.get('description') or '')[:160]))
        report.append(dict(name=v44, demo=n, origin=origin, bbox_dev_mm=None if dev is None else round(dev, 3), valid=valid))
        print(f'{len(names):3d} {v44[:60]:60s} dev={dev if dev is None else round(dev, 3)} {"cached " if rec else ""}{origin[:40]}', flush=True)
    print(f'part cache: {hits} of {len(names)} parts reused', flush=True)
    views = dict(complete=names, open=names,
                 drivetrain=[n for n in names if meta[n]['group'] in ('drivetrain', 'mounts')],
                 fairlead_rack=[n for n in names if meta[n]['group'] in ('fairlead',) or meta[n]['demo_name'].startswith(('FM9 Drum', 'REF_drum_shaft', 'FM10 Drum'))],
                 handle=[n for n in names if meta[n]['group'] in ('handle',) or 'motor_face' in n or 'motor_gusset' in n],
                 wiring=[n for n in names if meta[n]['group'] in ('electronics', 'power', 'wiring', 'mounts')])
    rev = dict(mode='', parts=names, colors=colors, meta=meta, joints=[], hardware=hardware, views=views, expected_interference=[],
               insert_reference=json.loads((R / 'print-v42/printed/revision.json').read_text())['insert_reference'],
               status='V44 phase 1 engineering preview: every live-demo part (design layout rev 12, 176 mm drum shaft) as real CAD. New base, enclosure and rack puck not built yet; no release checks.',
               engineering_preview=True, parent_revision='V42', source_layout='workbench/public/stock-battery-fit/design-layout-rev12.json',
               excluded=EXCLUDE, printer=dict(model='Bambu Lab P2S', build_volume_mm=[256, 256, 256]))
    for mode in ('cnc', 'printed'):
        (HERE / mode / 'revision.json').write_text(json.dumps(dict(rev, mode=mode), indent=1))
        with open(HERE / mode / 'hardware.csv', 'w', newline='', encoding='utf-8') as fh:
            w = csv.DictWriter(fh, fieldnames=['part', 'group', 'kind', 'size', 'source', 'note']); w.writeheader(); w.writerows(hardware)
    (HERE / 'phase1-report.json').write_text(json.dumps(report, indent=1))
    bad = [r for r in report if r['bbox_dev_mm'] is not None and r['bbox_dev_mm'] > 0.5 or not r['valid']]
    print('parts', len(names), 'bbox deviations > 0.5 mm or invalid:', len(bad))
    for r in bad: print('  CHECK', r)

if __name__ == '__main__':
    main()

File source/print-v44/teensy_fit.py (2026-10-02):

"""V44 W7: the Teensy 4.0 supplier CAD on its perfboard. Run after mock_models.py, before build_v44_fasteners.py (both variants).

The demo's Teensy is a drawn block: the KiCad Teensy 4.0 model (rectangular-body-study/vendor/teensy40.brep) never matched the
drawing-based mesh, so phase 1 kept the block. Here the vendor board is placed by rule on the block's perfboard:
  - USB end up (+Z), 2 mm below the perfboard top; components toward +Y; centred on the perfboard in X;
  - on 2 x 14-pin 2.54 mm socket headers (both long edges), the micro-USB receptacle centred on the right-angle plug mock.
Real header rows run the full length of both long edges, right where the 4 corner screws of the perfboard were (their heads sat
0.5 mm inside the Teensy outline). There is no room to grow the perfboard (regulator 2.6 mm below, CAN board 2 mm to the side),
so the perfboard takes 2 screws on the centreline between the header rows (12.7 mm channel, head 2.3 mm under the Teensy):
the standoffs move there and the plate's old corner holes are filled. Idempotent: everything is placed from the perfboard.
"""
from pathlib import Path
import json, sys
import cadquery as cq
from OCP.gp import gp_Trsf
from OCP.BRepBuilderAPI import BRepBuilderAPI_Transform

H = Path(__file__).resolve().parent
VEND = H.parent / 'rectangular-body-study/vendor/teensy40.brep'
V = cq.Vector
SOCKET = 4.85                      # perfboard face to Teensy underside (2.54 mm socket headers); puts the USB on the plug mock
USB_DROP = 2.0                     # receptacle top below the perfboard top
PITCH, ROWS = 2.54, 15.24          # header pitch, row spacing (0.6 in)
SCREW_IN = 6.0                     # centreline screws: this far in from the PCB ends
PLUG_R = 2.4                       # fill for the old M2.5 insert holes (3.6 + lead-in)
N_T, N_S, N_P = 'TRIAL_Teensy', 'MOUNT_Teensy_perfboard_standoffs', 'MOUNT_front_board_plate_printed'

def box(x0, x1, y0, y1, z0, z1): return cq.Solid.makeBox(x1 - x0, y1 - y0, z1 - z0, V(x0, y0, z0))
def ycyl(r, x, z, y0, y1): return cq.Solid.makeCylinder(r, y1 - y0, V(x, y0, z), V(0, 1, 0))
def thin(s): return [q for q in s.Solids() if q.BoundingBox().ylen < 2.2 and q.Volume() > 300]

vend = cq.Shape.importBrep(str(VEND))
vb = vend.BoundingBox()
pcb_v = max(vend.Solids(), key=lambda q: q.Volume()).BoundingBox()             # vendor PCB: X long, Y thickness (+Y components), Z width

def fit(variant):
    d = H / variant; r = json.loads((d / 'revision.json').read_text())
    if N_T not in r['parts']: return None
    old = cq.Shape.importBrep(str(d / (N_T + '.brep')))
    perf = max(thin(old), key=lambda q: q.Volume())                               # the perfboard (the old PCB block is the smaller one)
    pb = perf.BoundingBox(); cx = (pb.xmin + pb.xmax) / 2
    # world = (zv + tx, yv + ty, -xv + tz): USB (vendor -X end) up
    tx = cx - (pcb_v.zmin + pcb_v.zmax) / 2
    ty = pb.ymax + SOCKET - pcb_v.ymin
    tz = pb.zmax - USB_DROP + vb.xmin
    T = gp_Trsf(); T.SetValues(0, 0, 1, tx, 0, 1, 0, ty, -1, 0, 0, tz)
    board = cq.Shape.cast(BRepBuilderAPI_Transform(vend.wrapped, T, True).Shape())
    fch = sys.modules.get('fchist_rec')                                    # FreeCAD history (FCHIST=1): record the move
    if fch: fch.tag_xform(board, vend, [[0, 0, 1, tx], [0, 1, 0, ty], [-1, 0, 0, tz]])
    z0, z1 = tz - pcb_v.xmax, tz - pcb_v.xmin                                    # PCB ends (world Z)
    n = round((z1 - z0) / PITCH); zs = (z0 + z1) / 2 - n * PITCH / 2
    sockets = [box(cx + s * ROWS / 2 - PITCH / 2, cx + s * ROWS / 2 + PITCH / 2, pb.ymax, pb.ymax + SOCKET, zs, zs + n * PITCH) for s in (-1, 1)]
    teensy = cq.Compound.makeCompound([board, *sockets, perf])
    teensy.exportBrep(str(d / (N_T + '.brep'))); teensy.exportStep(str(d / (N_T + '.step')))

    # standoffs: same piece, now 2 on the centreline
    so = cq.Shape.importBrep(str(d / (N_S + '.brep'))).Solids()
    tpl = so[0]; tb = tpl.BoundingBox(); tc = ((tb.xmin + tb.xmax) / 2, (tb.zmin + tb.zmax) / 2)
    new_axes = [(cx, z0 + SCREW_IN), (cx, z1 - SCREW_IN)]
    old_axes = [((q.BoundingBox().xmin + q.BoundingBox().xmax) / 2, (q.BoundingBox().zmin + q.BoundingBox().zmax) / 2) for q in so]
    stand = cq.Compound.makeCompound([tpl.translate(V(x - tc[0], 0, z - tc[1])) for x, z in new_axes])
    stand.exportBrep(str(d / (N_S + '.brep'))); stand.exportStep(str(d / (N_S + '.step')))

    # plate: fill the old holes that no standoff uses any more
    filled = []
    if N_P in r['parts']:
        plate = cq.Shape.importBrep(str(d / (N_P + '.brep')))
        for x, z in old_axes:
            if min(abs(x - a) + abs(z - b) for a, b in new_axes) < 0.5: continue
            ring = plate.intersect(ycyl(PLUG_R + 1.0, x, z, -400, 400)).BoundingBox()  # plate material around the hole
            plate = plate.fuse(ycyl(PLUG_R, x, z, ring.ymin, ring.ymax)); filled.append((round(x, 2), round(z, 2)))
        plate = plate.clean()
        plate.exportBrep(str(d / (N_P + '.brep'))); plate.exportStep(str(d / (N_P + '.step')))

    m = r['meta'][N_T]
    m['source'] = 'CAD: vendor teensy40.brep (KiCad Teensy library) placed by rule + 2 x 14-pin socket headers + perfboard footprint from the demo'
    m['note'] = ('Teensy 4.0 (supplier CAD) on 2 x 14-pin 2.54 mm socket headers, %.2f mm off a 1.6 mm perfboard; USB up, micro-USB on the '
                 'right-angle plug. Perfboard: 2 x M2.5 on the centreline between the header rows (head under the Teensy - fit the '
                 'perfboard before plugging the Teensy in). Cut the VIN-VUSB pad.' % SOCKET)
    r['meta'][N_S]['note'] = '2 standoffs on the Teensy centreline (W7: corner screws would sit under the header rows).'
    (d / 'revision.json').write_text(json.dumps(r, indent=1))
    bb = board.BoundingBox()
    return dict(board=[round(v, 2) for v in (bb.xmin, bb.xmax, bb.ymin, bb.ymax, bb.zmin, bb.zmax)], pcb_z=(round(z0, 2), round(z1, 2)),
                screws=[(round(x, 2), round(z, 2)) for x, z in new_axes], filled=filled)

if __name__ == '__main__':
    rep = {v: fit(v) for v in ('printed', 'cnc')}
    for v, x in rep.items(): print(v, x)
    (H / 'teensy-fit.json').write_text(json.dumps(rep, indent=1))

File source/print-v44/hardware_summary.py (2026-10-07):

"""V44 buy list for the small hardware: counts every screw, nut, washer and insert of both builds (F44_* from
build_v44_fasteners.py) plus the modelled extras (exit pulley axles, board standoffs, socket headers) -> hardware-summary.md.
Run after build_v44_fasteners.py. Counts are exact for the model; buy a pack (or +10 %) of each."""
from pathlib import Path
import json, re, collections

H = Path(__file__).resolve().parent
EXTRA = [   # (part-name prefix, item, per match)
    ('FM10_Exit_pulley_U625ZZ', 'uxcell U625ZZ nylon U-groove pulley bearing 5 x 20 x 7', 1),
    ('FM10_Exit_axle_ISO7379_5x25_M4_shoulder', 'Shoulder bolt ISO 7379, 5 mm shoulder x 25, M4 thread', 1),
    ('FM10_Exit_axle_M5_spacer_2mm', 'M5 spacer / shim washer 2 mm (5.2 ID)', 1),
    ('FM10_Exit_axle_M4_washer', 'M4 washer (ISO 7089)', 1),
    ('FM10_Exit_axle_M4_nut', 'M4 nyloc nut (ISO 10511)', 1),
    ('MOUNT_Pi_ceiling_standoffs_M2.5', 'M2.5 female-female brass hex standoff 3 mm', 'solids'),
    ('MOUNT_BMS_ceiling_standoffs_M3', 'M3 female-female brass hex standoff / spacer 2 mm', 'solids'),
    ('TRIAL_Teensy', '2.54 mm 14-pin female socket header, low profile (Teensy on the perfboard)', 2),
]

def order(item):
    m = re.match(r'M(\d+(?:\.\d+)?)(?:x(\d+))?', item)
    return (0 if 'insert' in item else 1 if 'x' in item.split()[0] else 2, float(m.group(1)) if m else 99, int(m.group(2) or 0) if m else 0, item)

def count(variant):
    r = json.loads((H / variant / 'revision.json').read_text())
    c = collections.Counter(h['size'] for h in r['hardware'] if str(h['part']).startswith('F44_'))
    for pre, item, k in EXTRA:
        for n in r['parts']:
            if n.startswith(pre):
                if k == 'solids':
                    import cadquery as cq
                    k_ = len(cq.Shape.importBrep(str(H / variant / (n + '.brep'))).Solids())
                else: k_ = k
                c[item] += k_
    return c

cs = {v: count(v) for v in ('printed', 'cnc')}
items = sorted(set(cs['printed']) | set(cs['cnc']), key=order)
L = ['# V44 hardware buy list', '',
     'Generated by `print-v44/hardware_summary.py` from the model (every F44_* screw / nut / washer / insert, plus the exit',
     'axles, ceiling standoffs and Teensy socket headers). Counts are exact for each build; buy packs (assortment kits cover most',
     'screws). Printed = the PA-CF / PETG prototype; CNC = the aluminium-plate build. Nothing is ordered.', '',
     '| Item | Printed | CNC |', '|---|---:|---:|']
for it in items: L.append(f"| {it} | {cs['printed'].get(it, 0) or '-'} | {cs['cnc'].get(it, 0) or '-'} |")
tot = {v: sum(c.values()) for v, c in cs.items()}
L += [f"| **Total pieces** | **{tot['printed']}** | **{tot['cnc']}** |", '',
      '## Shopping by kit (printed build)', '']
kit = collections.defaultdict(lambda: collections.Counter())
for it, n in cs['printed'].items():
    m = re.match(r'M(\d+(?:\.\d+)?)x(\d+) (countersunk|socket head)', it)
    if m: kit[f"M{m.group(1)} {m.group(3)} screws"][int(m.group(2))] += n
    elif 'insert' in it: kit['heat-set inserts (Ruthex RX, L4)'][it.split()[0]] += n
    elif 'nut' in it or 'washer' in it: kit['nuts / washers'][it] += n
for k in sorted(kit):
    L.append(f"- **{k}:** " + ', '.join(f"{n} x {s}{' mm' if isinstance(s, int) else ''}" for s, n in sorted(kit[k].items(), key=lambda q: str(q[0]).zfill(4))))
L += ['', 'Hole sizes the model is cut to (tune with `fit-coupons/`): inserts M2.5 3.6 / M3 4.0 / M4 5.6 mm, printed clearance',
      'M2.5 2.9 / M3 3.6 / M4 4.7 / M6 6.8 mm, self-tap pilots M2.5 2.2 / M3 2.6 mm.', '']
(H / 'hardware-summary.md').write_text('\n'.join(L), encoding='utf-8')
print('\n'.join(L))

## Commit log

2026-10-02 Publish KINETIQ prototype hardware and redesigned build portal
    [01_inserts_M2.5_M3_M4.step, 01_inserts_M2.5_M3_M4.stl, 02_clearance_holes.step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]
2026-10-02 Point CAD links at the selected manufacturing variant
2026-10-04 Activate PayPal support for Carvera Air and prototypes (#4)
2026-10-07 CAD files: pending, not downloadable, until the validated release
    The four file tiles (FreeCAD, STEP, DXF, STL) linked to the repository's
    earlier prototype snapshot. They are now muted 'Pending' tiles with no
    link, and the section copy says the CAD, plate profiles and print files
    open with the next release.
2026-10-07 Plate & weldment kits: coming-soon notice in the CAD section
    Laser-cut, tapped and countersunk 6061 plate sets, or the welded and
    ground frame, rack mount and drum, made by the KINETIQ maker; available
    once the design is validated and load-tested. No checkout.
2026-10-07 Remove other companies' product names from the public repository
    The source folder print-v44-nano is now print-v44; build/audit_voltra_module10.py
    are now build/audit_fairlead_module10.py, and every reference follows. Design
    notes that named commercial products ("Nano-style handle loop", "VOLTRA-style
    twist-lock", "Voltra's centre piece") now describe the feature itself. No product
    names remain in tracked text or file names (scrubbed by the private repo's
    release/public_names.py, which future releases also apply).
    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
2026-10-08 Update the parts and price list to the current design
    The site's budget (site/data/project.json, parts.csv) was the v0.1.0
    list from October 2. It now follows the current BOM:
    - drive: MP80100 50 Kv motor ($230 + $30 shipping), Ruland MCLX-12-12-F
    clamp coupling, Loctite 638 for the drum hub and flanges;
    - level-wind: Tr8 x 2 lead screw, MGN15H rail, roller and thrust
    bearings, Sonic Hub (the worm, metal gears and REX parts are gone);
    - fairlead: 16008 swivel bearings, F6001 exit pulleys, shoulder bolts,
    dowel pins (the sheave, oval rings and nylon pulleys are gone);
    - fabrication: one laser-cut 0.250 in 6061 order and the drum tube
    (replaces the bottom plate, rear plate, face plate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
    [parts.csv]
2026-10-08 Budget: motor choices and a separate accessory list
    Follows the owner's list rules (October 7): the main list is only what a
    builder has to buy; shop stock most builders already have (USB isolator,
    grease, wire, terminals, ferrules, headers, perfboard, microSD, filament,
    foam, cable ties, thread locker, hitch pin, bar and carabiner, screws,
    nuts, washers, inserts) moves to an accessory list shown below the table
    and left out of the total.
    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
    [parts.csv]
2026-10-08 Budget: count printing and CNC as your own; outsourced metal parts listed apart
    The open-source budget assumes the builder owns a 3D printer and a CNC or
    laser and has the material (owner's call). The cut plates, drum tube and
    bearing cheeks move out of the main total into a "No CNC? Have the metal
    parts made" list beside the accessory list ($265 for the 150 lb builds,
    $310 for the servos). Filament was already in the accessory list.
    CNC build, main list: APS 8072S $1,401.08 · MP80100 $1,441.08 ·
    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
    [parts.csv]
2026-10-10 Budget: drop the AC servos; 220 lb peak on a Flipsky 75200 driver
    The Sanyo and Fuji servo choices and their parts are removed. The APS
    8072S is now the default 150 lb build, with the MP80100 as the second
    150 lb motor. Two 220 lb peak choices (MP80100 or APS C80100) use a
    Flipsky 75200 Pro V2 VESC driver and an AS5047P encoder board instead
    of the ODrive Pro, which stays with the 150 lb builds.
    [parts.csv]
2026-10-10 Budget: 220 lb peak on the ODrive Pro with a lower-Kv motor
    The Flipsky 75200 driver cannot fit inside the 220 lb build, so its
    driver and encoder board are removed. The two 220 lb choices now keep
    the ODrive Pro and use a lower-Kv winding instead: an APS C80100 wound
    to about 25 Kv (its own 429 mm build), or the MP80100 rewired from delta
    to wye (about 29 Kv) if it is wound delta. The ODrive Pro and its heat
    spreader apply to every motor again.
    [parts.csv]
2026-10-11 Budget: the Lite build on wall power, and a build comparison
    Adds the Lite build (APS 8072S wound ~25 Kv, ODrive S1, Mean Well
    LOP-600-36 supply, phone app and knob) as a build choice with its own
    buy list and current prices: S1 $149 (in stock at ODrive), LOP-600-36
    $105.34 (Jameco $83.60 plus the 26 % tariff), C14 inlet, rocker switch,
    brake resistors, XIAO ESP32-C3 and EC11 knob from Amazon. The battery,
    BMS, battery fusing, charge port, power switch, Pi, screen, Teensy and
    ODrive Pro lines now apply to the battery builds only. Main list: Lite
    $897.88 against $1,401.08 for the APS battery build.
    The budget section gets a table comparing every build's force,
    controller, power, size and mai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
    [parts.csv]
